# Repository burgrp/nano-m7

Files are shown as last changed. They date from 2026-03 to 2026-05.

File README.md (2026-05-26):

# Photon Mono M7 NanoDLP Modification

## Overview

Modification of the Anycubic Photon Mono M7 SLA printer to run NanoDLP. The original mainboard is replaced with a Raspberry Pi, a custom Nano-M7 controller board, and BHTM08 display driver. All mechanical parts and most electrical components are reused.

## Electronics

### Replaced
| Component | Replacement |
|---|---|
| Original mainboard | Raspberry Pi + Nano-M7 controller board + BHTM08 |

### Reused
- Display (DBM101M14K01) — driven by BHTM08 instead of original board
- UV lamp
- Z-axis stepper motor
- Limit switches
- Fans
- Power supply

## New Components

### Display Driver: BHTM08
- HDMI to MIPI DSI converter board by Shenzhen Aptus Technology
- Supports MONO LCD 9K/12K/14K
- Power: 5V via USB Type-C
- PCB size: 54x54mm, mounting holes φ3mm
- FPGA: Intel MAX 10 (10M13_9M16_V1.1)
- Interfaces: HDMI input, MIPI DSI output to display
- Spec: `doc/BHTM08 HDMI TO MIPI DSI DRIVER BOARD SPEC V1.0.pdf`

### CPU: Raspberry Pi
- Model TBD (Pi 4B or Pi 5 recommended for 14K image processing performance)
- Connected to Nano-M7 controller board via UART

### Nano-M7 Controller Board
- Custom board with connectors matching the original M7 control board for easy wiring
- PY32F030 MCU bridging the Raspberry Pi to printer peripherals
- See [Nano-M7 Controller Board](#nano-m7-controller-board-nano-m7kicad_sch) section for details

## Display: DBM101M14K01

- Manufacturer: Shenzhen Aptus Technology
- 10.1" TFT MONO (Transmissive), 13320x5120 pixels (14K)
- Outline: 230x142x1.06mm, Viewing area: 223.78x126.98mm
- Pixel size: 0.0168x0.0248mm
- Interface: 8-lane MIPI DSI, 51-pin FPC (connector: XVT:0-511822JT-5)
- Power: AVDD +5.5V, AVEE -5.5V, IOVCC 1.8V, IDD max 150mA
- Reset: active low, min 10µs pulse
- Spec: `doc/DBM101M14K01 Specification.pdf`

### NanoDLP Display Timing
| Parameter | Value |
|---|---|
| Resolution | 13320x5120 |
| Frame rate | 15 Hz |
| PCLK | 359 MHz |
| HACT | 4440 |
| HS | 10 |
| HBP | 72 |
| HFP | 74 |
| H_total | 4596 |
| VACT | 5120 |
| VS | 4 |
| VBP | 16 |
| VFP | 77 |
| V_total | 5217 |

## Original Mainboard Connectors

Original board connectors

Coordinates are XY in mm, origin at top-left corner of the board.

| Connector | Type | Pins | Position (mm) | Notes |
|---|---|---|---|---|
| Projector LCD panel | FPC | 50 | 0, 25 | MIPI DSI to DBM101M14K01 |
| UI LCD panel | FPC | 50 | 0, 60 | Touchscreen UI display |
| Build platform sensor | JST 2mm | 4 | 20, 46 | I2C, unknown sensor (possibly strain/force for release detection) |
| NTC thermistor | JST 2.54mm | 2 | 70, 80 | NTC 100k on UV lamp heatsink |
| Z-axis stepper | JST 2.54mm | 4 | 90, 0 | Z-axis stepper motor |
| Lamp PWM | JST 2.54mm | 2 | 105, 0 | UV lamp PWM control |
| Lamp fan 0 | JST 2.54mm | 2 | 83, 35 | UV lamp cooling fan |
| Lamp fan 1 | JST 2.54mm | 2 | 93, 35 | UV lamp cooling fan |
| Lamp power supply | Latched, 3.75mm | 2 | 115, 25 | Power to UV lamp (connector type TBD) |
| Main power input | Terminal block | 2 | 115, 12 | Input from main PSU |
| External USB | JST 2mm | 5 | 116, 67 | External USB port |
| Front panel button | JST 2.54mm | 4 | 110, 50 | Power button + LED (TBC) |
| Low Z stop | JST 2.54mm | 3 | 85, 56 | Z-axis min endstop |
| PRO model interface | JST 2mm | 8 | 116, 50 | Interface for PRO variant (function TBD) |
| WiFi | IPX | 1 | 80, 60 | WiFi module connector |

## Nano-M7 Controller Board (nano-m7.kicad_sch)

Custom MCU board based on PY32F030K1xTx bridging the Raspberry Pi / NanoDLP controller to the printer's peripherals.

### MCU Pin Assignment

| GPIO | Net | Direction | Function |
|---|-----|---|---|
| PF0 | Crystal | — | 16 MHz HSE in |
| PF1 | Crystal | — | 16 MHz HSE out |
| PF2 | NRST | — | Reset |
| PA0 | LAMP_NTC_MCU | IN | NTC thermistor ADC |
| PA2 | I2C_SDA | I/O | Build platform sensor |
| PA3 | I2C_SCL | I/O | Build platform sensor |
| PA4 | Z_STOP_LOW | IN | Z-axis min endstop |
| PA5 | FP_BTN | IN | Front panel button |
| PA6 | LAMP_PWM | OUT | UV lamp PWM |
| PA7 | LAMP_FAN_MCU | OUT | Lamp fan P-MOS gate |
| PA8 | ZS_STEP | OUT | Z stepper STEP |
| PA9 | PY_RXD | IN | UART RX from Raspberry Pi |
| PA10 | PY_TXD | OUT | UART TX to Raspberry Pi |
| PB1 | LED | OUT | Status LED |
| PB3 | LAMP_POWER_MCU | OUT | UV lamp power P-MOS gate |
| PB4 | ZS_DIR | OUT | Z stepper DIR |
| PB5 | FP_LED | OUT | Front panel LED |

### Command Interface

Communication between NanoDLP (Raspberry Pi) and MCU is via UART at 115200 baud (PA9/PA10).

Custom non-standard command set (not GCODE-compatible).

| Command | Parameters | Description |
|---|---|---|
| `ZH` | — | Home Z axis to min endstop |
| `ZM` | `S<steps> F<Hz>` | Move Z relative by steps at step frequency F (Hz). Positive = up, negative = down. |
| `GET` | — | Report Z position (Z:n steps), endstop (ES:0/1), button (BTN:0/1), temperature (NTC:n°C) |
| `LFE` | — | Lamp fan enable (P-MOS) |
| `LFD` | — | Lamp fan disable (P-MOS) |
| `LPE` | — | UV lamp power enable (P-MOS) |
| `LPD` | — | UV lamp power disable (P-MOS) |
| `LPI` | `I<0-255>` | Set UV lamp PWM intensity |
| `FPLE` | — | Front panel LED on |
| `FPLD` | — | Front panel LED off |
| `SCHI` | `I<ms>` | Set system check interval in ms |

### Controller Board to Raspberry Pi 4 wiring

Wired by ribbon cable:

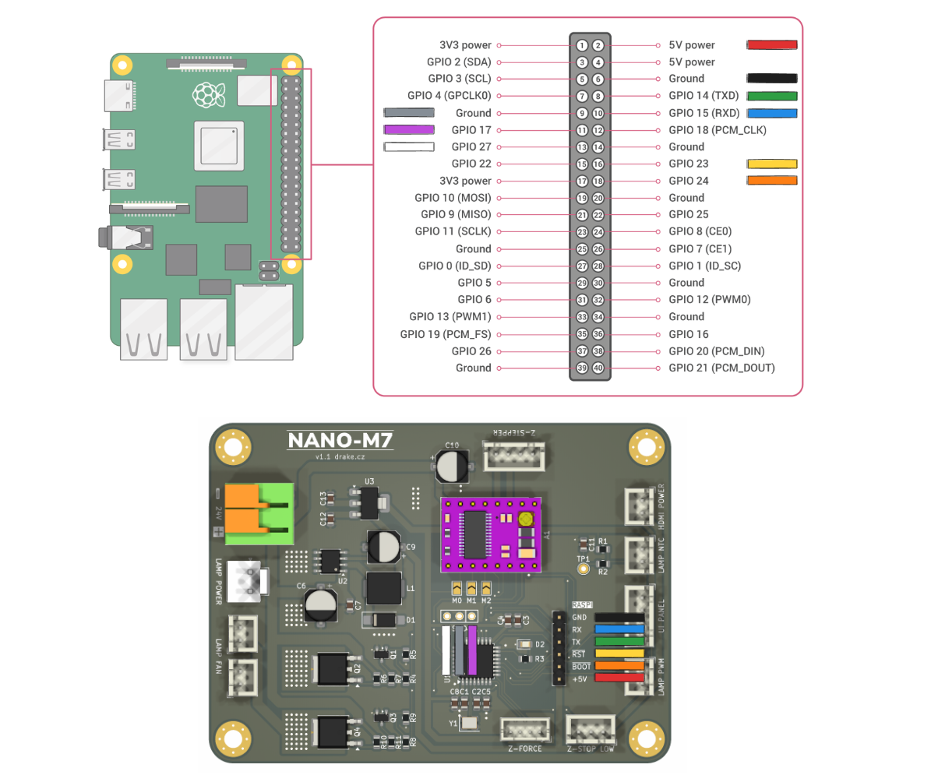
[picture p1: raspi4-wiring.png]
wiring


## Verified

- BHTM08 works correctly with DBM101M14K01
- Tested by connecting a notebook via HDMI to BHTM08, which drove the display successfully

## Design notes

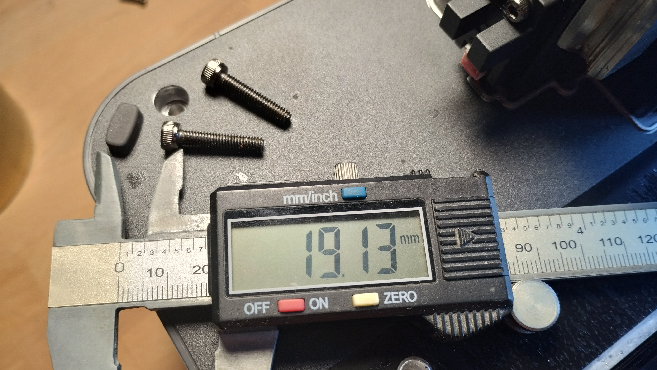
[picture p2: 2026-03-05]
doc/teardown-2026-03-05/IMG_20260305_130557422_HDR.jpg

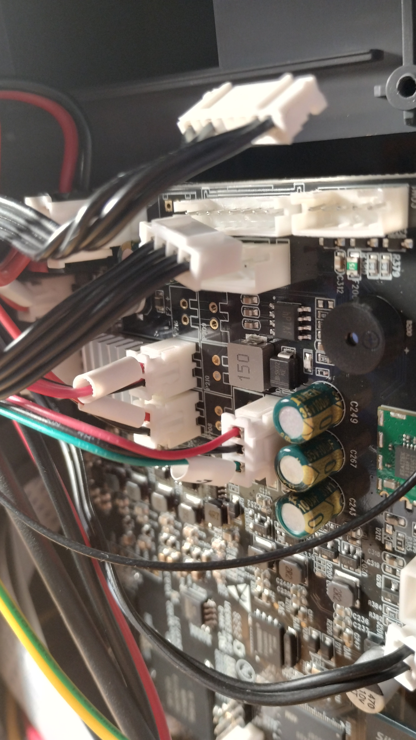
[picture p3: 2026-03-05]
doc/teardown-2026-03-05/IMG_20260305_123727216_HDR.jpg

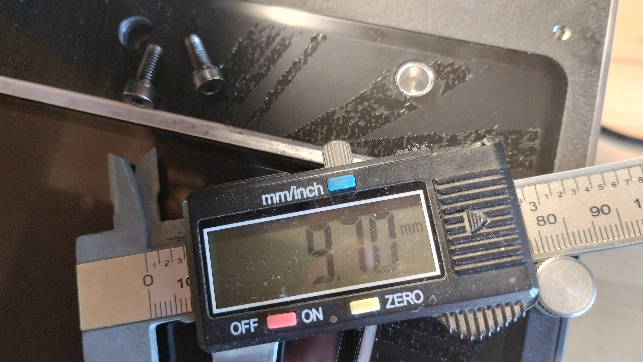
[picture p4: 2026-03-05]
doc/teardown-2026-03-05/IMG_20260305_130704003_HDR.jpg

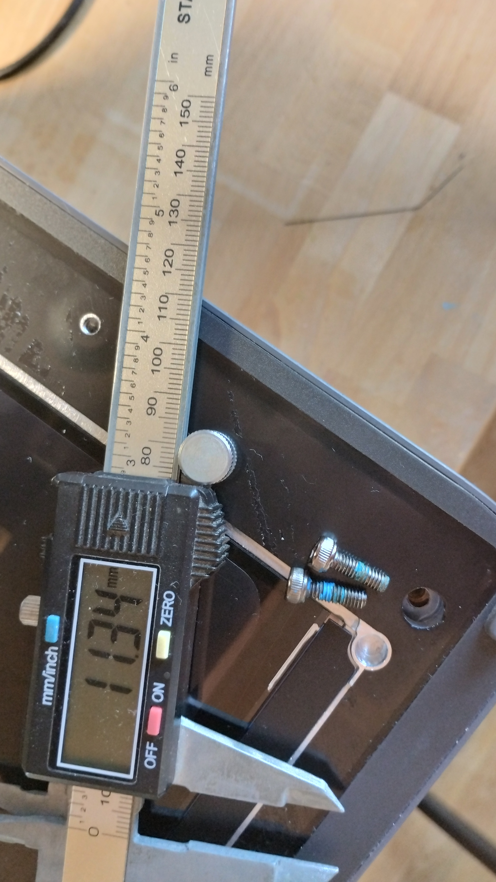
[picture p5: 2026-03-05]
doc/teardown-2026-03-05/IMG_20260305_130639690_HDR.jpg

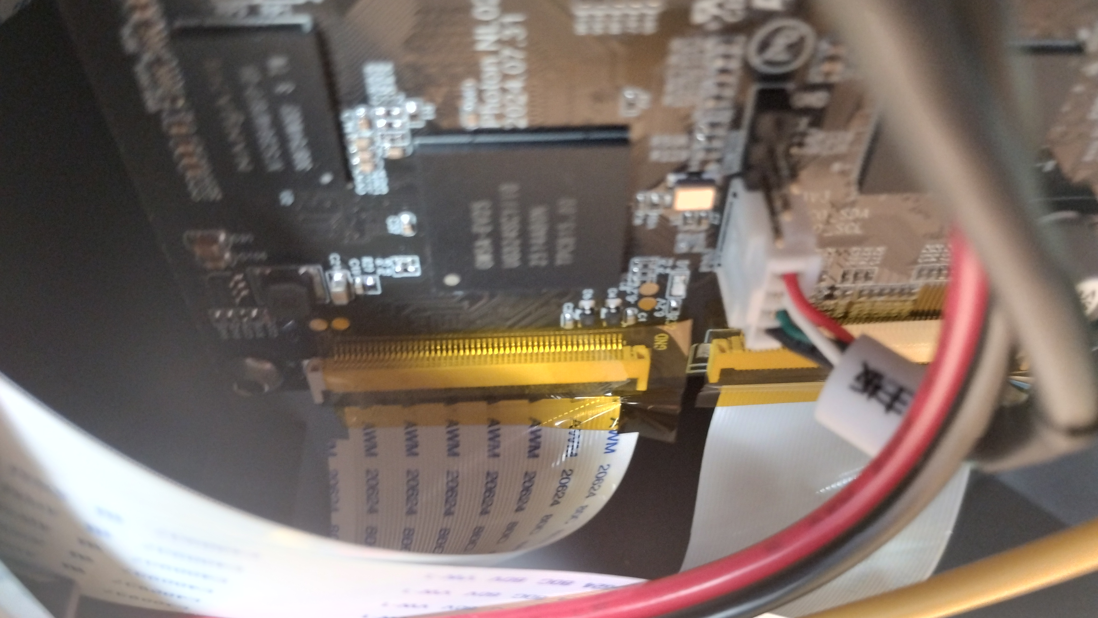
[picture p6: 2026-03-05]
doc/teardown-2026-03-05/IMG_20260305_123410823_HDR.jpg

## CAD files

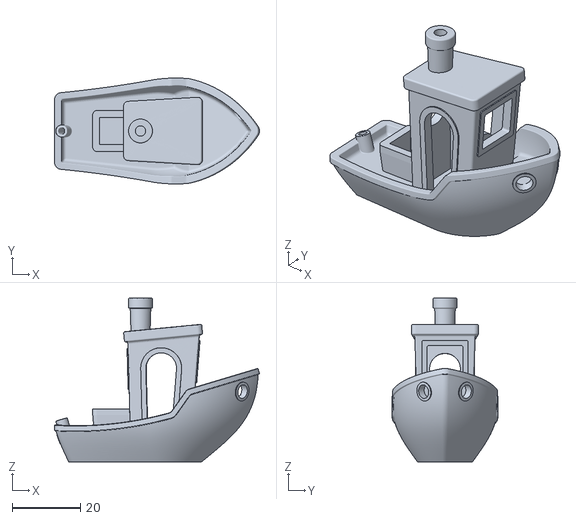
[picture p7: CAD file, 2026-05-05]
3DBenchy.stl
60.0 x 31.0 x 48.0

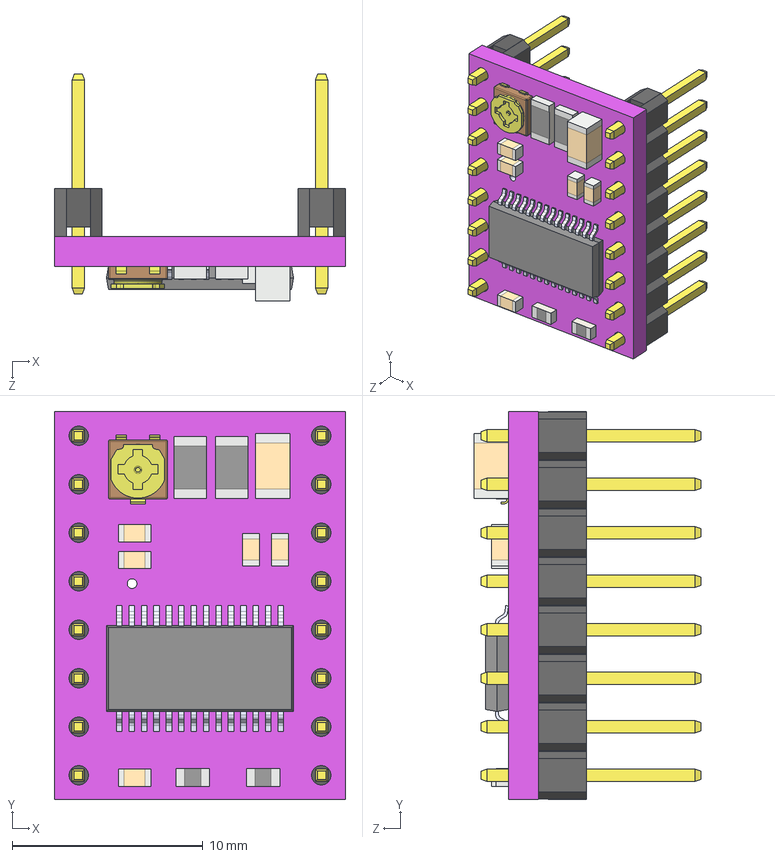
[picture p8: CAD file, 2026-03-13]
peri-board/drv8825-stepper-motor-driver-carrier-high-current.step
15.2 x 20.3 x 11.9 mm

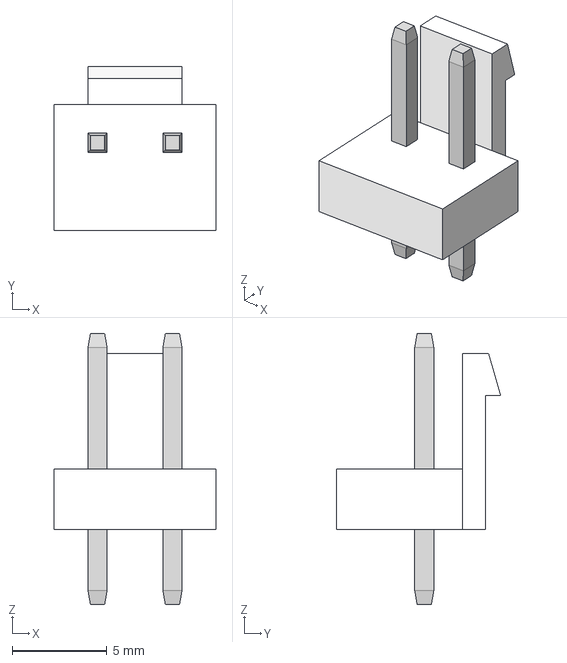
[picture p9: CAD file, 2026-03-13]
peri-board/JST - VH - Thru (V) - 2Pin - 3.96mm.stp
8.56 x 8.69 x 14.3 mm

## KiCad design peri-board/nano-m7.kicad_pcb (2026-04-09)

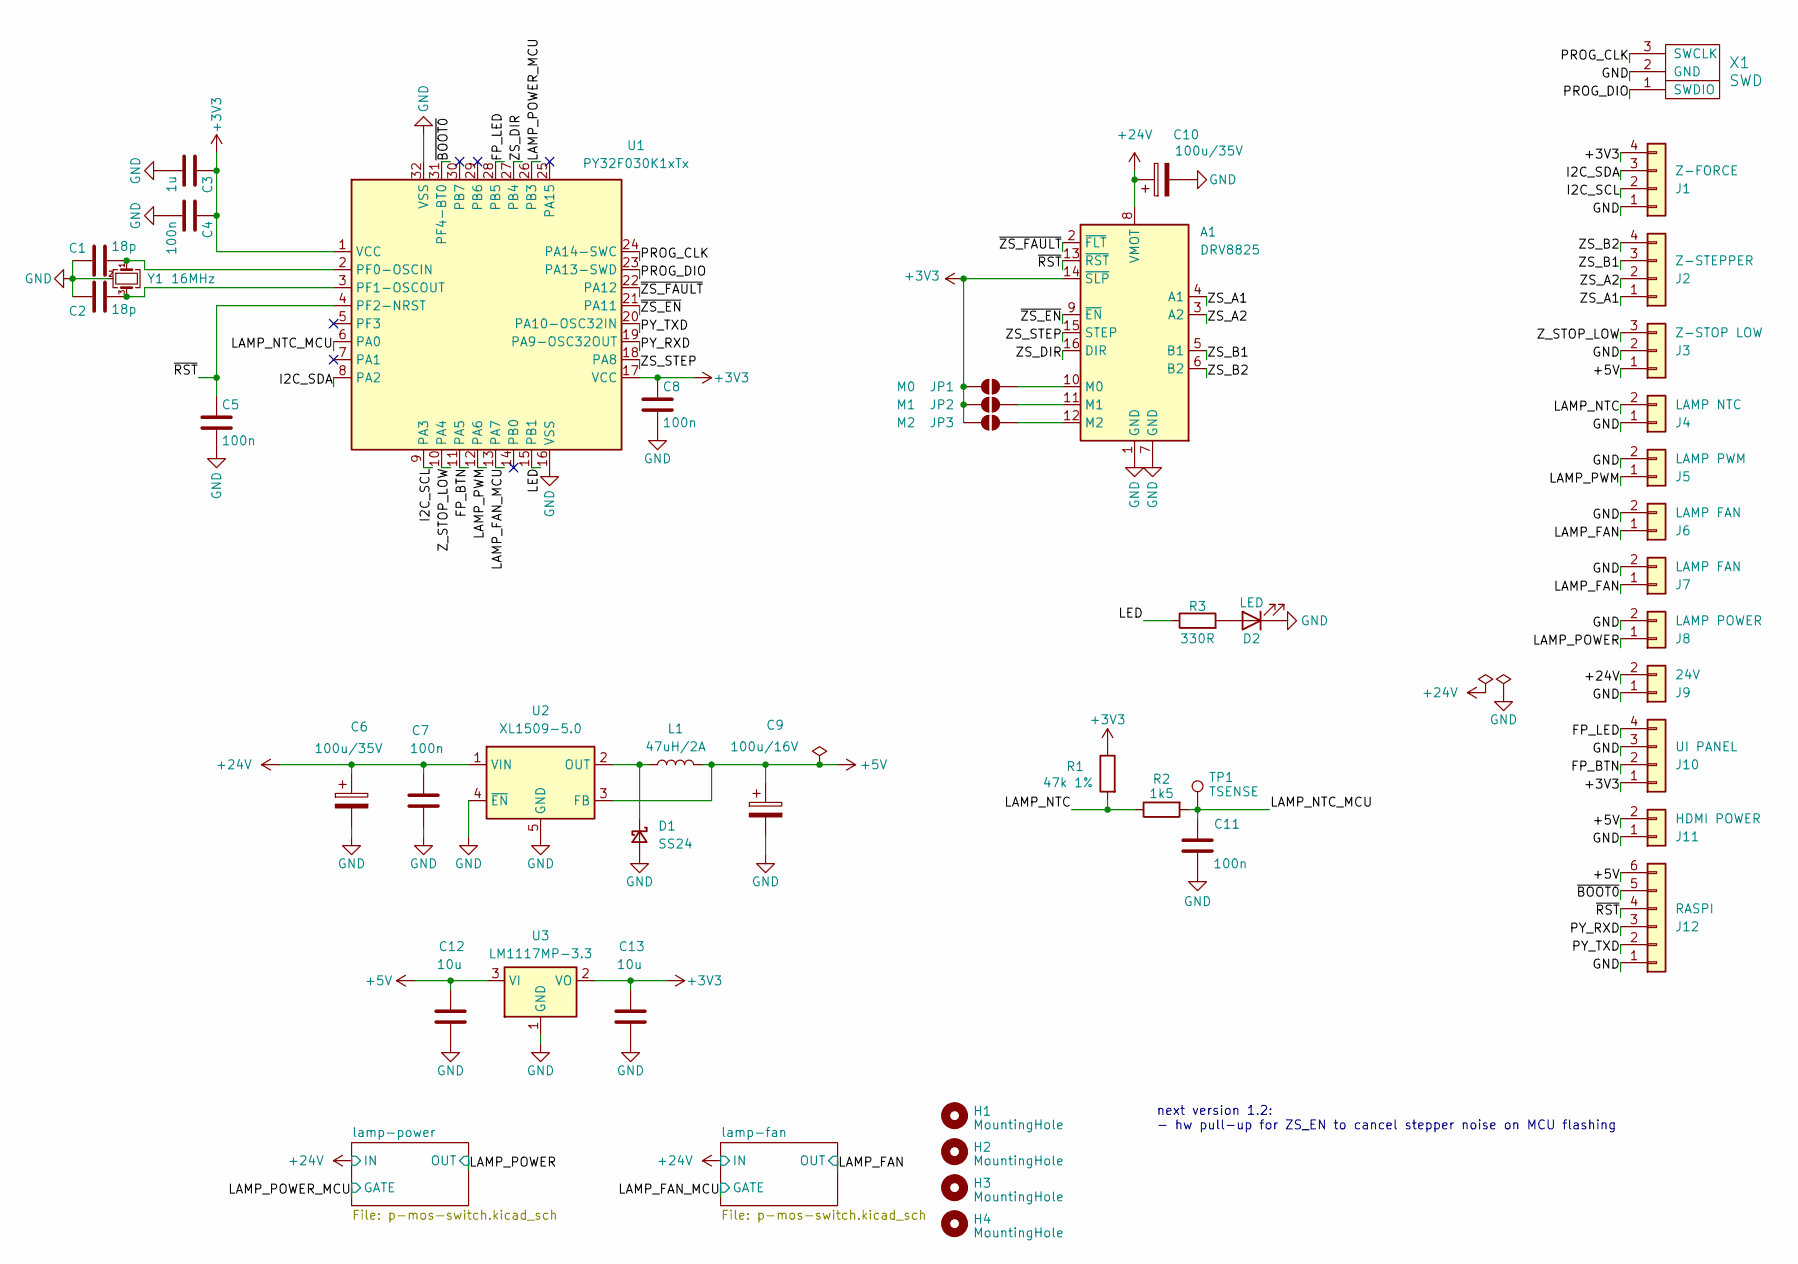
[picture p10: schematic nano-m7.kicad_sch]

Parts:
A1: DRV8825; Pololu_Breakout-16_15.2x20.3mm
C1, C2: 18p; C_0805_2012Metric
C3: 1u; C_0805_2012Metric
C4, C5, C7, C8, C11: 100n; C_0805_2012Metric
C6: 100u/35V; CP_Elec_6.3x5.8
C9: 100u/16V; CP_Elec_6.3x5.8
C10: 100u/35V; CP_Elec_6.3x5.8; LCSC C178540
C12, C13: 10u; C_0805_2012Metric
D1: SS24; D_SMA_Handsoldering
D2: LED; LED_0805_2012Metric
H1, H2, H3, H4: MountingHole; MountingHole_3.7mm_Pad_Via
J1: Z-FORCE; JST_PH_B4B-PH-K_1x04_P2.00mm_Vertical
J2: Z-STEPPER; JST_XH_B4B-XH-A_1x04_P2.50mm_Vertical
J3: Z-STOP LOW; JST_XH_B3B-XH-A_1x03_P2.50mm_Vertical
J4: LAMP NTC; JST_XH_B2B-XH-A_1x02_P2.50mm_Vertical
J5: LAMP PWM; JST_XH_B2B-XH-A_1x02_P2.50mm_Vertical
J6, J7: LAMP FAN; JST_XH_B2B-XH-A_1x02_P2.50mm_Vertical
J8: LAMP POWER; JST_VH_B2P-VH-B_1x02_P3.96mm_Vertical
J9: 24V; DG142R-2-5.08
J10: UI PANEL; JST_XH_B4B-XH-A_1x04_P2.50mm_Vertical
J11: HDMI POWER; JST_XH_B2B-XH-A_1x02_P2.50mm_Vertical
J12: RASPI; PinHeader_1x06_P2.54mm_Vertical
JP1: M0; SolderJumper-2_P1.3mm_Open_TrianglePad1.0x1.5mm
JP2: M1; SolderJumper-2_P1.3mm_Open_TrianglePad1.0x1.5mm
JP3: M2; SolderJumper-2_P1.3mm_Open_TrianglePad1.0x1.5mm
L1: 47uH/2A; L_Sunlord_MWSA0604S; LCSC C49190176
R1: 47k 1%; R_0805_2012Metric
R2: 1k5; R_0805_2012Metric
R3: 330R; R_0805_2012Metric
TP1: TSENSE; TestPoint_THTPad_D2.0mm_Drill1.0mm
U1: PY32F030K1xTx; LQFP-32_7x7mm_P0.8mm
U2: XL1509-5.0; SOIC-8_3.9x4.9mm_P1.27mm
U3: LM1117MP-3.3; SOT-223-3_TabPin2
X1: SWD
Y1: 16MHz; Crystal_SMD_3225-4Pin_3.2x2.5mm

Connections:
+3V3: A1.14 (~SLP), C3.1, C4.1, C8.1, C13.1, J1.4, J10.1, JP1.1 (A), JP2.1 (A), JP3.1 (A), R1.1, U1.1 (VCC), U1.17 (VCC), U3.2 (VO)
+5V: C9.1, C12.1, J3.1, J11.2, J12.6, L1.2, U2.3 (FB), U3.3 (VI)
+24V: A1.8 (VMOT), C6.1, C7.1, C10.1, J9.2, U2.1 (VIN); also elsewhere on the board
/FP_BTN: J10.2, U1.11 (PA5)
/FP_LED: J10.4, U1.28 (PB5)
/I2C_SCL: J1.2, U1.9 (PA3)
/I2C_SDA: J1.3, U1.8 (PA2)
/LAMP_FAN: J6.1, J7.1; also elsewhere on the board
/LAMP_FAN_MCU: U1.13 (PA7); also elsewhere on the board
/LAMP_NTC: J4.2, R1.2, R2.1
/LAMP_NTC_MCU: C11.2, R2.2, TP1.1, U1.6 (PA0)
/LAMP_POWER: J8.1; also elsewhere on the board
/LAMP_POWER_MCU: U1.26 (PB3); also elsewhere on the board
/LAMP_PWM: J5.1, U1.12 (PA6)
/LED: R3.1, U1.15 (PB1)
/PROG_CLK: U1.24 (PA14-SWC), X1.3 (SWCLK)
/PROG_DIO: U1.23 (PA13-SWD), X1.1 (SWDIO)
/PY_RXD: J12.3, U1.19 (PA9-OSC32OUT)
/PY_TXD: J12.2, U1.20 (PA10-OSC32IN)
/ZS_A1: A1.4 (A1), J2.1
/ZS_A2: A1.3 (A2), J2.2
/ZS_B1: A1.5 (B1), J2.3
/ZS_B2: A1.6 (B2), J2.4
/ZS_DIR: A1.16 (DIR), U1.27 (PB4)
/ZS_STEP: A1.15 (STEP), U1.18 (PA8)
/Z_STOP_LOW: J3.3, U1.10 (PA4)
/~BOOT0: J12.5, U1.31 (PF4-BT0)
/~RST: A1.13 (~RST), C5.1, J12.4, U1.4 (PF2-NRST)
/~ZS_EN: A1.9 (~EN), U1.21 (PA11)
/~ZS_FAULT: A1.2 (~FLT), U1.22 (PA12)
GND: A1.1 (GND), A1.7 (GND), C1.1, C2.1, C3.2, C4.2, C5.2, C6.2, C7.2, C8.2, C9.2, C10.2, C11.1, C12.2, C13.2, D1.2 (A), D2.1 (K), J1.1, J3.2, J4.1, J5.2, J6.2, J7.2, J8.2, J9.1, J10.3, J11.1, J12.1, U1.16 (VSS), U1.32 (VSS), U2.4 (~EN), U2.5 (GND), U2.6 (GND), U2.7 (GND), U2.8 (GND), U3.1 (GND), X1.2 (GND), Y1.2 (G), Y1.4 (G); also elsewhere on the board
unnamed: A1.10 (M0), JP1.2 (B)
unnamed: A1.11 (M1), JP2.2 (B)
unnamed: A1.12 (M2), JP3.2 (B)
unnamed: D1.1 (K), L1.1, U2.2 (OUT)
unnamed: D2.2 (A), R3.2
unnamed: C1.2, U1.2 (PF0-OSCIN), Y1.1
unnamed: C2.2, U1.3 (PF1-OSCOUT), Y1.3

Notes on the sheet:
next version 1.2: - hw pull-up for ZS_EN to cancel stepper noise on MCU flashing

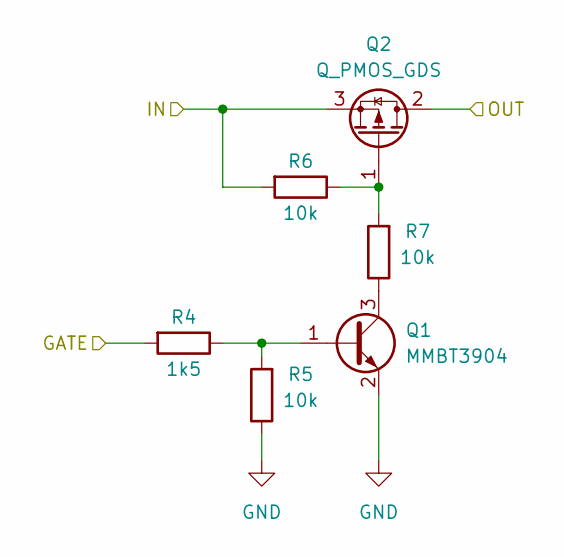
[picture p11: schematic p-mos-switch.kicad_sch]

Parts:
Q1: MMBT3904; SOT-23
Q2: Q_PMOS_GDS; TO-252-2
R4: 1k5; R_0805_2012Metric
R5, R6, R7: 10k; R_0805_2012Metric

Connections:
+24V: Q2.3 (S), R6.2; also elsewhere on the board
/LAMP_POWER: Q2.2 (D); also elsewhere on the board
/LAMP_POWER_MCU: R4.2; also elsewhere on the board
GND: Q1.2 (E), R5.1; also elsewhere on the board
unnamed: Q1.1 (B), R4.1, R5.2
unnamed: Q1.3 (C), R7.1
unnamed: Q2.1 (G), R6.1, R7.2

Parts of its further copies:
Q3: MMBT3904; SOT-23
Q4: Q_PMOS_GDS; TO-252-2
R8: 1k5; R_0805_2012Metric
R9, R10, R11: 10k; R_0805_2012Metric

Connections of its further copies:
+24V: Q4.3 (S), R10.2; also elsewhere on the board
/LAMP_FAN: Q4.2 (D); also elsewhere on the board
/LAMP_FAN_MCU: R8.2; also elsewhere on the board
GND: Q3.2 (E), R9.1; also elsewhere on the board
unnamed: Q3.1 (B), R8.1, R9.2
unnamed: Q3.3 (C), R11.1
unnamed: Q4.1 (G), R10.1, R11.2

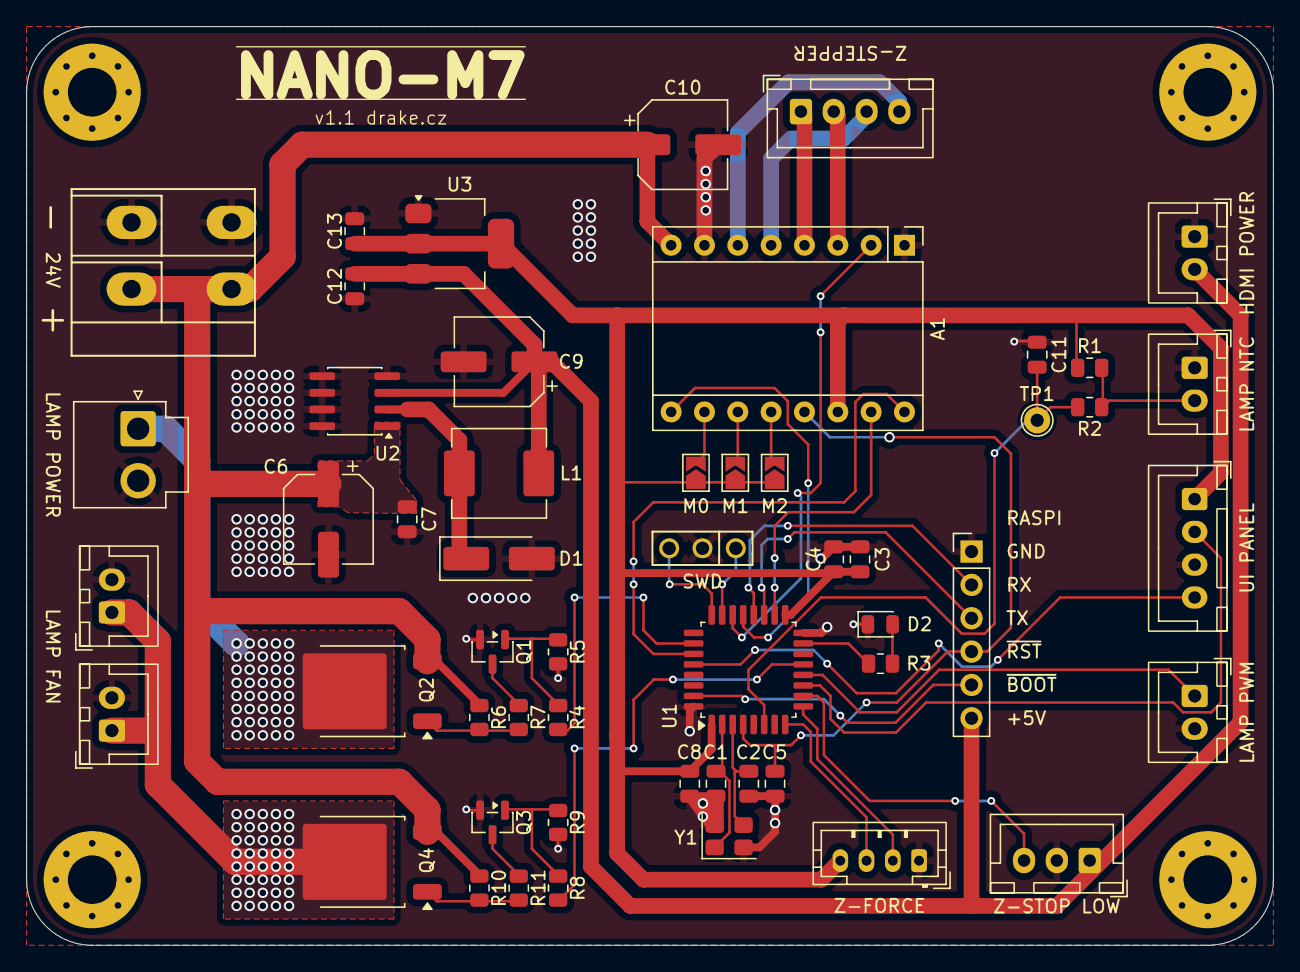
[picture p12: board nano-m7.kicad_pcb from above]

Board: 2 copper layers, 95.0 x 70.0 mm, 57 parts (0 on the bottom side), 44 nets.

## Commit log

2026-03-13 board v1.0
    [JST - VH - Thru (V) - 2Pin - 3.96mm.stp, dcdc.kicad_sch, drv8825-stepper-motor-driver-carrier-high-current.step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]
2026-03-31 Update documentation and code structure
    - Corrected the path for TinyGo source code in CLAUDE.md
    - Updated plot directory in nano-m7.kicad_pro
    - Removed lock file ~nano-m7.kicad_sch.lck
    - Enhanced Makefile with garbage collection options
    - Updated main.go to set clock frequency and configure UART pins
    - Modified size-report.html for accurate size representation
2026-04-05 Add pin configuration for lamp fan and implement M801 GCode command for fan control
2026-04-05 Add lamp PWM control and update main function for new pin configuration
2026-04-05 Update lamp initialization to include timer parameter and enable TIM3 peripheral clock in main function
2026-04-05 Remove redundant LED pin configuration from main function and ensure it's set in syscheck initialization
2026-04-05 Add front panel functionality with LED control and update main logic
2026-04-05 Implement front panel and Z-axis functionality with reporting capabilities
2026-04-05 Remove note on lamp power activation from README
2026-04-05 Update README to clarify controller board naming and connection details
2026-04-05 Add notes on new 5V source and LDO requirements to schematic
    [nano-m7.kicad_sch]
2026-04-06 Update lamp and z-axis functionality with NTC thermistor integration and ADC setup
2026-04-06 Enhance Z-axis functionality with stepper motor control and ISR integration; update front panel button configuration
    [nano-m7.kicad_sch]
2026-05-04 Refactor UART pin configuration for clarity and consistency
2026-05-04 Add ZAxis enable pin and update related functionality
2026-05-04 Update schematic text for next version 1.2 with hardware pull-up for ZS_EN
    [nano-m7.kicad_sch]
2026-05-04 Add initial implementation of NanoM7 host application
    - Create JSON profile for default print settings.
    - Implement display management using SDL2 for rendering images.
    - Set up Go module and dependencies for the project.
    - Develop main application logic to initialize store, serial communication, and display.
    - Implement printer control logic with state management and job handling.
    - Add serial communication client for sending commands and receiving status.
    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
2026-05-05 Refactor printer setup and slicing logic; add STL parsing and ZIP output functionality
2026-05-05 Add HDMI output support and profiling options; refactor STL parsing logic
2026-05-05 Remove unused components and default profile
    - Deleted the default print profile (1.json) from the profiles directory.
    - Removed the display package and its associated functionality from the host.
    - Eliminated the main application logic in main.go, including server setup and initialization.
    - Removed the printer package, which handled printing logic and state management.
    - Deleted the serial communication client used for printer communication.
    - Removed the store package responsible for managing profiles and plates.
    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
    [3DBenchy.stl]
2026-05-05 Add 3DBenchy STL file for benchmarking
    [3DBenchy.stl]
2026-05-05 Add initial firmware and hardware support for Nano-M7
    - Create symbol library table for KiCad with Drake and MCU_Puya_PY32F.
    - Add .gitignore file to peri-fw to exclude build artifacts.
    - Implement Makefile for building, flashing, and testing the firmware.
    - Add GCode command handler in handler.go for processing GCode commands.
    - Implement unit tests for GCode command handler in handler_test.go.
    - Initialize Go module for firmware in go.mod.
    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
    [JST - VH - Thru (V) - 2Pin - 3.96mm.stp, drv8825-stepper-motor-driver-carrier-high-current.step, nano-m7.kicad_pcb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]
2026-05-14 feat: Upgrade Font Awesome to version 7.2.0 and update styles
    - Updated Font Awesome CSS files to version 7.2.0, including changes to font-family and deprecated properties.
    - Added new font files for Nunito Sans (Black, Bold, Regular) to enhance UI typography.
    - Enhanced common CSS with new styles for navigation and printer name display.
    - Refactored common.js to improve the decoration function and update printer name dynamically.
    - Modified home.page.js to reflect updated title and structure.
    - Cleaned up ui_api.go by removing unused status management code.
    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
